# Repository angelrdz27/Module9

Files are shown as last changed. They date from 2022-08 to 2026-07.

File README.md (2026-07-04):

# Module9

This module contains all the tasks.

## Flexible Prosthetic Hand project

An out-of-the-box answer to "commercial prosthetic hands are too stiff":
instead of building a rigid hand and softening it, build a **soft hand that
stiffens on demand**. Passive fin-ray fingers conform with zero computation,
one servo drives all fingers through a self-balancing differential, and a
granular-jamming pad locks the hand rigid only when it needs to carry load.

### Documentation
| File | What it covers |
|---|---|
| `prosthetic-hand-design.md` | Design philosophy & concept directions |
| `finray-cad-print-parameters.md` | Fin-ray geometry & TPU print settings |
| `hardware-research.md` | Component research & ~$150 / ~$400 BOMs |
| `architecture.md` | System architecture (mechanical / electrical / firmware / software) |
| `ROADMAP.md` | Phased development plan with exit criteria |
| `PROCUREMENT.md` | Phase 0 order checklist + toolchain setup |
| `docs/wiring-schematic.md` | Full electrical schematic & connection tables |
| `docs/assembly-guide.md` | Step-by-step build instructions |
| `docs/test-protocol.md` | Validation tests mapped to roadmap exit criteria |

### Build artifacts
| Directory | Contents |
|---|---|
| `cad/` | Parametric OpenSCAD models (fin-ray finger, whiffle-tree, palm chassis, wrist/socket, pad mold) |
| `firmware/` | ESP32-S3 control firmware (grasp FSM, STS3215 driver, EMG intent, jamming) |
| `software/` | EMG collection, classifier training, and fatigue cycle-test scripts |
| `docs/` | Wiring schematic, assembly guide, test protocol |
| `build/` | Pre-rendered, manifold-checked STLs + preview PNGs (ready to slice) |
| `attacksurface.md` | Running security inventory of every system/vendor/tech + its exposure |
| `.claude/skills/attack-surface/` | Skill that maintains `attacksurface.md` |
| `.claude/workflows/AssessAttackSurface.js` | Workflow that assesses a surface & recommends test cadence |

### Quick start
1. Read `ROADMAP.md`; order the starter BOM via `PROCUREMENT.md`.
2. Slice the ready-made STLs in `build/stl/` (no CAD tool needed), or
   regenerate with `cad/render_all.sh` after editing parameters.
3. Flash `firmware/prosthetic_hand/`, drive it over serial (`c`/`o`).
4. Add EMG: `cd software && python emg_train.py --selftest` to check the
   pipeline, then collect real data and train.

### Current status
Phase 0/1 **design & toolchain complete**: all 12 parts render to
manifold-checked STLs (`build/`), the firmware compiles, and the EMG pipeline
passes its self-test. Remaining Phase 0/1 items are the physical
print-and-measure steps (`docs/test-protocol.md` T1–T4).

---

### Original task (Session 12)
See `Homework-12_MTMP.md` — dining philosophers problem.

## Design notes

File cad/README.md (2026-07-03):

# CAD — parametric OpenSCAD models

All parts are driven by the parameter blocks at the top of each file.
Open in OpenSCAD (or run `openscad -o out.stl file.scad` headless).

## Files
- `finray_finger.scad` — the fin-ray finger. Also contains the fingertip
  silicone-pad drape mold (`part = "mold"`).
- `whiffletree.scad` — 3-rocker tendon differential print plate.
- `palm_chassis.scad` — palm/chassis: finger + thumb mounts, servo pocket,
  tendon routing, jamming-pad recess, wrist bolt circle.
- `wrist_socket.scad` — wrist adapter (`part="adapter"`) + parametric forearm
  socket cuff (`part="cuff"`, scale to limb circumference measurements).

## Generating the finger set
Render four STLs by overriding `finger_length` (all other params shared):

```bash
for f in index:80 middle:88 ring:82 pinky:65; do
  name=${f%%:*}; len=${f##*:}
  openscad -o finger_${name}.stl -D finger_length=${len} finray_finger.scad
done
```

Thumb: reuse the index finger (80 mm) mounted on the palm at ~45° opposition.

## Variants to print in Phase 1 (see ../ROADMAP.md)
| Variant | Override |
|---|---|
| Baseline | (defaults) |
| Floating ribs | `-D floating_gap=0.4` |
| Graded wall | `-D front_wall_t=1.4 -D front_wall_t_tip=0.8` |

## Material / print quick reference
| Part | Material | Notes |
|---|---|---|
| Fingers | TPU 95A | Print lying on side face (as modeled); dry filament first |
| Rockers | PETG/PLA+ | Flat, 4 walls, 30% gyroid |
| Palm chassis | PETG/PLA+ | Palm-down, 4 walls, 30% gyroid, heat-set M3 inserts |
| Wrist adapter | PETG | Flat |
| Socket cuff | TPU 95A | Compliant, comfortable; scale to limb measurements |
| Pad mold | PLA | 0.12 mm layers, smooth cavity with brief heat-gun pass |

Full settings: `../finray-cad-print-parameters.md`.

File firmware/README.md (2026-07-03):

# Firmware — ESP32-S3 hand controller

Arduino sketch in `prosthetic_hand/`. Requires the ESP32 Arduino core
(board: "ESP32S3 Dev Module"). No external libraries — the Feetech
STS3215 driver is the self-contained `sts_servo.h`.

## Wiring

| ESP32-S3 GPIO | Connects to | Notes |
|---|---|---|
| 17 (TX1) | STS3215 data line **through 1 kΩ resistor** | half-duplex trick |
| 18 (RX1) | STS3215 data line (direct) | |
| 4 | MyoWare 2.0 ENV output | ADC1_CH3, sensor powered at 3.3 V |
| 5 | Pump MOSFET gate (logic-level N-FET, e.g. IRLZ44N/AO3400) | flyback diode across pump |
| 6 | Valve MOSFET gate | flyback diode across solenoid; energized = sealed |
| 7 | Momentary button to GND | manual open/close override |
| 15 | Status LED (+ resistor) | solid = HOLDING, blink = idle |
| GND | common ground with servo/pump supply | **required** |

Power: servo + pump from 2S Li-ion (7.4–12 V, ≥5 A BMS); ESP32 from USB or a
buck converter. Never power the servo from the devkit's 5 V pin.

A Waveshare "Bus Servo Adapter" (~$6) replaces the resistor trick if you
prefer a clean TTL interface.

## Serial interface (115200 baud)

| Command | Effect |
|---|---|
| `c` / `o` | close / open |
| `g<0-100>` | grip effort → servo load limit |
| `j` / `v` | jam / vent the stiffening pad |
| `e` | toggle EMG mode (runs 2×3 s calibration: relax, then squeeze) |
| `?` | status line |

Telemetry streams as CSV at 10 Hz:
`millis,emg_raw,emg_env,state,servo_pos,servo_load,jammed`
(state: 0=OPEN 1=CLOSING 2=HOLDING 3=RELEASING). Feed it to
`../software/emg_collect.py` or the Arduino serial plotter.

## Calibration on first assembly
1. With tendons slack, send `o`, then set `POS_OPEN` to the servo's current
   position (`?`).
2. Manually close the fingers, note the position, set `POS_CLOSED`.
3. Grip an object and watch `servo_load` in telemetry; tune `GRIP_LOAD`
   (stop-closing threshold) and `JAM_LOAD` (auto-stiffen threshold).

## EMG intent scheme (v1, single channel)
- Sustained squeeze above 35 % of calibrated range → **close**.
- Two quick pulses within 600 ms → **open** (so a long squeeze can't
  accidentally drop the object).
- Upgrade path: 3-class classifier from `../software/emg_train.py`.

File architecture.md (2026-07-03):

# System Architecture — Flexible Prosthetic Hand

## 1. System overview

```mermaid
flowchart LR
    subgraph User
        M[Forearm muscles]
    end
    subgraph Sensing
        E[MyoWare 2.0 EMG<br/>envelope out]
    end
    subgraph Controller["ESP32-S3"]
        A[ADC + filtering]
        S[Grasp state machine]
        B[STS3215 bus driver<br/>UART half-duplex]
        J[Jamming controller<br/>2x MOSFET]
    end
    subgraph Actuation
        SV[Feetech STS3215 servo]
        W[Whiffle-tree differential]
        F[4x fin-ray fingers + thumb]
    end
    subgraph Stiffness
        P[Vacuum pump]
        V[3-way solenoid valve]
        PAD[Granular jamming pad]
    end

    M --> E --> A --> S
    S --> B --> SV --> W --> F
    S --> J
    J --> P --> PAD
    J --> V --> PAD
    SV -- present load/position --> B
```

Three layers of compliance, each handling a different timescale:

| Layer | Mechanism | Timescale | Controlled by |
|---|---|---|---|
| Passive | Fin-ray wrap + silicone pads | instant | geometry (no control) |
| Grasp | Whiffle-tree tendon differential | ~0.5 s | servo position + load |
| Stiffness | Granular jamming pad | ~1–2 s | pump + valve |

Design rule: intelligence lives as low in the stack as possible. The fingers
conform with zero computation; the servo only decides *how much* to close;
firmware only decides *when* to stiffen.

## 2. Mechanical architecture

```
[STS3215 servo] -- horn --> [primary rocker 50mm]
                              /              \
              [secondary rocker 40mm]   [secondary rocker 40mm]
                 /        \                /         \
             [index]   [middle]        [ring]     [pinky]
```

- Each rocker pivots freely at its midpoint: when one finger contacts an
  object, its tendon stops moving and the rocker rotates, routing the
  remaining travel to the sibling finger. Four fingers self-balance with
  zero sensors.
- Thumb: fixed opposed position in v1 (printed at 45° opposition). v2 option:
  a Feetech SCS0009 micro bus servo on the same UART bus for abduction.
- Tendon run: servo horn → primary rocker → secondary rocker → PTFE tube
  through palm → fin-ray back-wall channel → figure-8 stopper knot at tip
  anchor. Return force: fin-ray elasticity itself (no extensor tendon in v1).
- Tensioning: each rocker end hole is a slot with an M3 grub-screw clamp so
  UHMWPE creep can be taken up without re-knotting.

Key travel calculation: full finger flexion needs ~18 mm of tendon travel.
Servo horn radius 12 mm × 120° usable sweep = 25 mm at the primary bar —
margin of ~1.4×, absorbed by the differential.

## 3. Electrical architecture

| Net | Source | Consumers | Notes |
|---|---|---|---|
| VBAT 7.4–12 V | 2S Li-ion + BMS | STS3215, pump (via MOSFET) | Servo is happiest at 7.4–12 V |
| 5 V | Buck from VBAT | MyoWare shield, solenoid | MyoWare 2.0 accepts 3.3–5 V |
| 3.3 V | ESP32 devkit LDO | ESP32-S3, logic | |

### Pin map (ESP32-S3 DevKitC; see firmware/README.md)

| GPIO | Function | Direction |
|---|---|---|
| 17 | UART1 TX → STS3215 data (through 74HC126 or direct with 1k resistor trick) | out |
| 18 | UART1 RX ← STS3215 data | in |
| 4 | EMG envelope (ADC1_CH3) | in |
| 5 | Pump MOSFET gate | out |
| 6 | Solenoid valve MOSFET gate | out |
| 7 | Mode button (INPUT_PULLUP) | in |
| 15 | Status LED | out |

The STS3215 uses single-wire half-duplex TTL. Cheapest interface: tie TX to
the data line through a 1 kΩ resistor and connect RX directly — TX idles high
and the resistor lets the servo win the line when replying. A Waveshare bus
driver board (~$6) is the tidy alternative.

### Power budget (worst case)
| Load | Current |
|---|---|
| STS3215 stall @12 V | ~2.5 A (limit in firmware to 1.5 A equiv. load) |
| Vacuum pump | ~0.4 A |
| Solenoid | ~0.2 A |
| ESP32 + EMG | ~0.15 A |
| **Peak** | **~3.2 A** → 2S 18650 pack (≥5 A rated BMS) is sufficient |

## 4. Firmware architecture (`firmware/prosthetic_hand/`)

Single-core superloop at 100 Hz (no RTOS needed at this rate):

```
loop @100Hz:
  emg_sample()        # ADC read → 20-sample moving average → envelope
  intent = classify() # dual-threshold hysteresis (or serial command)
  fsm_step(intent)    # OPEN / CLOSING / HOLDING / RELEASING
  servo_update()      # goal position; stop closing when load > limit
  jamming_update()    # stiffen when HOLDING && load high; vent on release
  telemetry @10Hz     # CSV over USB serial for plotting / data collection
```

### Grasp state machine

| State | Entry condition | Servo behavior | Jamming |
|---|---|---|---|
| OPEN | release intent / boot | goal = open position | vented |
| CLOSING | close intent | ramp toward closed at fixed speed | vented |
| HOLDING | servo load > grip threshold, or full travel | hold position, duty-limit if hot | stiffen if load > jam threshold for >1 s |
| RELEASING | open intent | ramp to open | vent immediately (valve first, then pump off) |

Load-based grip: instead of position targets per object, the servo closes
until *present load* (register 60) crosses the grip threshold — the
mechanical differential + fin-rays have already shaped the grasp by then.
This is impedance-ish control with zero tactile sensors.

### EMG intent (v1: single channel)
- Calibration at boot: 3 s of rest → noise floor; user squeezes once → max.
- Close intent: envelope > 35 % of (max − floor), with 150 ms debounce.
- Open intent: quick double-pulse within 600 ms (co-contraction pattern),
  so a single sustained squeeze can't accidentally open the hand.
- v2 (`software/`): 3-class ML classifier (rest/close/open) on windowed
  features, exported thresholds or TFLite-Micro model.

## 5. Software architecture (`software/`)
- `emg_collect.py` — logs the firmware's 10 Hz telemetry CSV to labeled
  session files (`rest.csv`, `close.csv`, `open.csv`).
- `emg_train.py` — windows the data (200 ms, 50 % overlap), extracts
  MAV / RMS / waveform-length / zero-crossings, trains a RandomForest,
  reports confusion matrix, and prints firmware-ready threshold constants.
  TFLite-Micro export is the documented upgrade path.

## 6. Interfaces & contracts
- **Serial command protocol** (USB, 115200 baud, newline-terminated):
  `o` open, `c` close, `g<0-100>` grip effort, `j`/`v` jam/vent, `?` status.
  This is also the test interface for Phase 2 before EMG exists.
- **Telemetry CSV**: `millis,emg_raw,emg_env,state,servo_pos,servo_load,jammed`
- **CAD ↔ hardware contract**: all printed parts reference the parameter
  block at the top of each `.scad` file; tendon channel Ø2.5 mm, PTFE 2 mm OD,
  M3 fasteners throughout.

## 7. Failure-mode behavior
| Failure | Detection | Response |
|---|---|---|
| Servo over-load / stall | present load > 90 % for 2 s | back off 5°, duty-limit |
| EMG sensor unplugged | envelope pinned at rail | freeze state, LED blink, fall back to serial commands |
| Vacuum loss (membrane leak) | pump duty > 80 % sustained | disable jamming, notify via telemetry |
| Brown-out under stall | ESP32 brown-out detector | servo torque-off on reboot, hand stays passively compliant (fail-soft — a key advantage over rigid hands) |

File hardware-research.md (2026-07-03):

# DIY Flexible Prosthetic Hand — 2025/2026 Component Research & BOM

*Scope: TPU fin-ray fingers, fishing-line tendons, single-servo whiffletree
differential, silicone fingertip pads, with later granular-jamming stiffness
and EMG control. All prices are **approximate** (USD, mid-2026) and shift with
retailer/quantity.*

---

## 1. Actuators

The architecture uses **one main actuator** pulling a whiffletree, so you want
high stall torque, position feedback (ideally), and enough travel to close all
fingers. Serial-bus servos win here because they give torque + encoder
feedback + daisy-chaining on 3 wires, which matters once you add EMG and want
current-based grip feedback.

| Model | Type | Stall torque | Size / weight | Interface | Price (approx) |
|---|---|---|---|---|---|
| **Feetech STS3215** (C018, 12V) | Serial bus, magnetic encoder | ~30 kg·cm @12V (19.5 kg·cm @7.4V C001) | 40×20×40 mm, ~60 g | TTL serial bus (daisy-chain), 12-bit abs encoder | **~$14–27 each** |
| **Dynamixel XC330-M288-T** | Serial bus, metal gear | ~0.6 N·m (~6 kg·cm) | ~34 mm tall, ~23 g | TTL, 4096-step encoder, current/temp feedback | ~$45–55 |
| **Dynamixel XL330-M288-T** | Serial bus, plastic gear | 0.52 N·m (~5.3 kg·cm) @5V | 20×34×26 mm, **18 g** | TTL serial bus, full feedback | ~$27 |
| **DS3218 / DS3218MG** (ANNIMOS) | Standard PWM digital, metal gear | 19–21.5 kg·cm | 40×20×40.5 mm, ~60 g | PWM (no feedback) | ~$15–20 |
| **Actuonix PQ12-63-12-S** | Micro linear actuator | 30 N push @ 8 mm/s, 20 mm stroke | ~34 mm body | PWM/analog + position feedback | ~$70–90 |
| **Actuonix L12** | Linear actuator (longer stroke) | up to ~40–80 N depending on gearing | 50–100 mm stroke | PWM/RC/analog | ~$70–110 |

**Picks:**
- **Pick the Feetech STS3215 if** you want the best torque-per-dollar and
  position/current feedback for a whiffletree main pull — it's the de-facto
  open-source robotics servo (SO-ARM100/101) and is cheap enough to buy
  spares. **Recommended default.**
- **Pick the Dynamixel XL330/XC330 if** weight and clean feedback
  (current-based grip sensing) matter more than cost, e.g. a wearable
  prosthesis where 18 g and precise control beat raw torque.
- **Pick the DS3218 if** you just want the cheapest strong "pull the tendon
  bundle" actuator for a first mechanical prototype and will do position
  control open-loop off a microcontroller PWM pin.
- **Linear actuator (Actuonix PQ12/L12) if** you prefer a direct linear tendon
  pull with built-in position feedback and no horn geometry — cleaner force
  curve, but pricier and slower.

---

## 2. Tendon Materials

Both Spectra and Dyneema are UHMWPE (same fiber family); "PE braid" fishing
line is the accessible form. Key properties: **near-zero stretch,
steel-comparable strength-to-weight, excellent abrasion resistance**, but it
*creeps* under sustained load and can saw through soft plastic anchors, so
route through PTFE and use metal/round anchor points.

| Material | Recommended rating | Behavior | Use for |
|---|---|---|---|
| **Braided UHMWPE (Spectra/Dyneema/PE braid)** — e.g. PowerPro, Berkley | **50–100 lb test** for a full-hand main tendon; 30–50 lb for individual fingers | Very low stretch, high fatigue life, low friction; slowly creeps, needs good knots (Palomar) or crimps | **Primary tendon material — recommended** |
| **Nylon monofilament** | 30–80 lb | Stretches noticeably (elastic return can help passive extension), UV/fatigue weaker, cheaper | Return/antagonist springs, non-critical routing, prototyping |
| **Bowden cable (steel inner + housing)** | n/a (steel) | No stretch, high push/pull, heavier, more friction | Long routing runs through the forearm where you need push as well as pull |
| **PTFE tube (Bowden liner, 2 mm OD / ~1 mm ID, "Capricorn"-style)** | — | Ultra-low-friction routing sheath; keeps braid from sawing plastic | Route tendons around every direction change |

**Picks:**
- **Pick 65–80 lb PE braid + PTFE liner if** you want the standard, reliable
  tendon setup (a 100 lb PowerPro line is exactly what research tendon-driven
  hands like the Seed Robotics RH8D use). **Recommended.**
- **Pick nylon mono if** you specifically want built-in stretch for passive
  finger extension, or as a cheap disposable prototype line.
- **Add short PTFE tube segments** at all fin-ray entry/exit points and pulley
  bends — this is the single biggest longevity upgrade for fishing-line
  tendons (~$8–12 for 1 m of Capricorn tube).

*Cost: a spool of quality PE braid is ~$15–25 and will last many builds.*

---

## 3. EMG Sensing (later iteration)

| Board | Channels | Interface | Ease | Price (approx) |
|---|---|---|---|---|
| **MyoWare 2.0 Muscle Sensor** (SparkFun DEV-21265) | 1 (envelope + raw out) | Analog out, snap-on shields (LED/power/cable/BLE) | Easiest — plug-and-play, wearable, shield ecosystem | ~$38 (sensor); Basic/Wireless kits ~$70–110 |
| **BioAmp EXG Pill** (Upside Down Labs) | 1 (EMG/ECG/EOG/EEG) | Analog out to any ADC | Easy, needs gel electrodes + cable; publication-grade signal | ~$25–35 each (2-pack ~$69) |
| **uMyo** (Ultimate Robotics / uDevices) | 1 wireless + IMU | BLE / nRF24 / USB, 9 g wearable PCB | Easy wireless, great for untethered; add nRF24 to read on Arduino | ~$30–40 |
| **Gravity / OYMotion (DFRobot SEN0240 etc.)** | 1 | Analog | Easy, robust analog front-end | ~$35–45 |

**Picks:**
- **Pick MyoWare 2.0 if** you want the lowest-friction start: it outputs a
  clean rectified envelope you can threshold on any ADC pin, and the shield
  ecosystem (power, BLE, cable) is genuinely beginner-friendly.
  **Recommended first EMG.**
- **Pick BioAmp EXG Pill if** you want the best signal quality per dollar and
  plan to do real ML classification — you get the raw waveform for feature
  extraction, and it's cheap enough to run 2–3 channels for multi-gesture
  control.
- **Pick uMyo if** you want wireless, wearable EMG (untethered forearm band)
  with an onboard IMU for sensor-fusion gestures.

*For TinyML multi-gesture control, budget 2–3 channels (e.g. 3× BioAmp EXG
Pill ≈ $75–90).*

---

## 4. Microcontrollers

| Board | CPU / ML | Wireless | Notes | Price (approx) |
|---|---|---|---|---|
| **ESP32-S3** (DevKit / XIAO ESP32-S3) | Dual-core 240 MHz, vector/SIMD for ML inference | Wi-Fi + BLE | Best all-rounder: enough ADC channels, cheap, huge community, runs TFLite-Micro; XIAO form factor fits in a forearm | ~$8–15 |
| **Teensy 4.0 / 4.1** | Cortex-M7 @600 MHz (overclock ~1 GHz) | none (4.1 has Ethernet) | Fastest MCU here; excellent ADC + tons of PWM/serial for many servos; ideal if you outgrow ESP32 compute | ~$20–30 |
| **Arduino Nano 33 BLE Sense (Rev2)** | Cortex-M4F @64 MHz + IMU | BLE | The canonical TinyML board — best-documented TensorFlow Lite Micro workflow, onboard IMU | ~$45–55 |
| **RP2040 / RP2350 (Pico 2)** | Dual M0+/M33; RP2350 adds more compute | RP2350 W has Wi-Fi/BLE | Cheap, PIO is great for driving many servos/serial buses precisely | ~$4–8 |

**Picks:**
- **Pick ESP32-S3 if** you want one board to do servo control + EMG ADC +
  future on-device ML + wireless telemetry. Best value and future-proofing.
  **Recommended default.**
- **Pick Teensy 4.x if** your EMG classifier gets heavy (higher sample rates,
  more channels, real-time DSP) — raw horsepower and superb peripheral count.
- **Pick Nano 33 BLE Sense if** you're following TinyML tutorials directly —
  the gesture/EMG classification toolchain is most turnkey here.
- **Pick RP2350/Pico 2 if** you want a rock-bottom-cost controller and will
  use PIO to bit-bang the Feetech serial bus and PWM cleanly.

---

## 5. Granular Jamming Supplies (iteration 2)

The classic "coffee-balloon" universal jamming gripper (Brown/Amend/Jaeger,
PNAS 2010) is the reference; here you'd apply it as **variable-stiffness
pads/palm**.

| Item | Options | Notes | Price (approx) |
|---|---|---|---|
| **Vacuum pump** | 12V mini diaphragm (SparkFun ROB-10398 style); **SC3101PM** (Skoocom, very small 3–5V); generic 6–12V diaphragm | Diaphragm pumps are one-way (can't reverse to inflate). ~-40 to -70 kPa is plenty for jamming | ~$15–30 |
| **Solenoid valve** | 2-way/3-way 6–12V normally-closed (e.g. small barbed pneumatic solenoid) | Lets you hold vacuum without running pump; 3-way vents to atmosphere to un-jam fast | ~$6–12 |
| **Membrane** | Latex balloons / party balloons; thin latex sheet; nitrile finger cots for small pads | Balloons are the cheap standard; latex sheet lasts longer | ~$5–10 |
| **Granular media** | **Ground coffee** (low density, best jamming-hardness/weight — the classic pick); **glass beads** (harder grip, heavier); ground rice/sand as alternatives; EPS/soft beads give *higher* force but less rigidity | Coffee = best all-round for lightweight pads; glass beads if you want maximum rigidity | ~$5 |
| Check valve + barbed fittings + silicone tubing | 4 mm / 6 mm ID tubing | Plumbing | ~$8 |

**Picks:**
- **Pick a 12V mini diaphragm pump + 3-way solenoid + coffee-filled latex pad
  if** you want the proven, cheapest variable-stiffness route. **Recommended.**
- **Pick glass beads if** you need maximum locked rigidity (heavier);
  **coffee grounds if** weight matters (fingertip/palm pads).
- Budget ~$40–55 total for a working single-chamber jamming subsystem.

---

## 6. Silicone for Fingertip Pads

| Product | Shore hardness | Feel / use | Buy small qty | Price (approx) |
|---|---|---|---|---|
| **Ecoflex 00-30** (Smooth-On) | Shore 00-30 (very soft), ~900% elongation | Skin-like, grippy, deformable fingertip pads; skin-safe | Trial unit (~1 lb total) | **~$40–52 trial** |
| **Dragon Skin 10** (Smooth-On) | Shore 10A (firmer, tougher) | More durable, higher tear strength; good for structural fin-ray reinforcement or grippier tougher pads | Trial unit | ~$40–55 trial |
| **Ecoflex 00-50** | 00-50 (mid) | Compromise: softer than Dragon Skin, tougher than 00-30 | Trial unit | ~$45 |

**Picks:**
- **Pick Ecoflex 00-30 if** you want maximally compliant, high-friction,
  skin-like fingertip pads for adaptive grasp. **Recommended for pads.**
- **Pick Dragon Skin 10 if** you want durability/tear resistance (pads that
  survive abrasion, or flexible joint webbing).
- Buy **trial units** direct from Smooth-On or resellers (Douglas & Sturgess,
  Reynolds); one trial kit casts many fingertip pads. Add a
  **Slacker/Thi-Vex** additive later if you want softer or thixotropic
  (non-drip) mixes.

---

## 7. TPU Filaments (fin-ray fingers)

Fin-ray fingers need flexibility but enough backbone to transmit tendon
force — **95A is the sweet spot** for fin-ray; 85A for very compliant tips;
Varioshore lets you grade stiffness within one print.

| Filament | Shore | Printability | Price/kg (approx) |
|---|---|---|---|
| **NinjaFlex 85A** (NinjaTek) | 85A, ~660% elong | Softest common FDM TPU; **direct-drive only**, 20–25 mm/s, no retraction, must be dry | ~$45 |
| **NinjaTek Cheetah 95A** | 95A | Engineered to print on **Bowden** extruders too; forgiving, fast | ~$40–50 |
| **Polymaker PolyFlex TPU95** | 95A | Easy, reliable, good surface | ~$30 |
| **eSUN TPU 95A** | 95A | Best value, widest colors incl. translucent; QC "good not great" | **~$20** |
| **Overture TPU 95A** | 95A | Cheap, reliable budget option | ~$20–25 |
| **colorFabb varioShore TPU** | **~92A (60–70% flow) down to ~55A fully foamed** | Foaming — vary stiffness/density by temp & flow (200–250 °C expands ~1.6×); great for graded fin-ray | ~$52 |

**Picks:**
- **Pick eSUN or Overture TPU 95A if** you want cheap, reliable fin-ray
  fingers and have a direct-drive printer. **Recommended default for
  structure.**
- **Pick NinjaTek Cheetah 95A if** you're on a Bowden printer (Ender-style) —
  it's specifically formulated not to jam.
- **Pick NinjaFlex 85A if** you want very compliant fingers/webbing and have
  direct drive + patience.
- **Pick varioShore TPU if** you want to grade stiffness within a single
  finger (stiff base → soft tip) — ideal for advanced fin-ray tuning.

---

## 8. Reference Open-Source Projects

- **Yale OpenHand Project** (GrabLab) — the canonical open-source
  underactuated hand line (Model T, T42, M2, etc.): 3D-printed,
  tendon-driven, differential/underactuated fingers. **Study first — closest
  to this architecture.** eng.yale.edu/grablab/openhand
- **Whiffletree differential papers** — Kontoudis & Kyriakopoulos /
  Leddy & Dollar; the Frontiers/PMC review *"On Differential Mechanisms for
  Underactuated, Lightweight, Adaptive Prosthetic Hands"* and the
  *selectively-lockable whiffletree* work (144 postures from one motor).
  **Essential reading for the single-servo differential.**
- **exiii HACKberry** — fully open 3D-printable EMG bionic hand
  (Arduino-based, ~$200 BOM). exiii-hackberry.com — good for EMG integration
  + socket/wrist design.
- **Open Bionics — Brunel Hand 2.0** — open design files on GitHub
  (Open-Bionics/Brunel) and Thingiverse; tendon-driven, research-grade. Good
  mechanical reference.
- **Tactile SoftHand-A** (arXiv 2406.12731, 2024) — 3D-printed,
  highly-underactuated anthropomorphic hand with **antagonistic tendons** +
  tactile sensing. Recent and directly relevant to soft tendon hands.
- **e-NABLE / LimbForge** — community body-powered and simple designs
  (Phoenix Hand, Unlimbited Arm); best for socket, cosmesis, and fit patterns
  rather than actuation.
- **HANDSON Hand (CYBATHLON 2024, PMC11939478)** — recent competition-grade
  design notes worth skimming for real-world robustness lessons.

---

## Suggested ~$150 Starter BOM (mechanical proof-of-concept)

*Goal: TPU fin-ray fingers, fishing-line tendons, single-servo whiffletree,
silicone pads, basic microcontroller control.*

| Item | Choice | Qty | Price (approx) |
|---|---|---|---|
| Main actuator | Feetech STS3215 (serial bus, feedback) | 1 | $20 |
| Microcontroller | ESP32-S3 (XIAO or DevKit) | 1 | $12 |
| Servo/bus driver + wiring | TTL bus adapter + buck converter + connectors | 1 | $12 |
| TPU filament | eSUN / Overture TPU 95A, 1 kg | 1 | $22 |
| Tendon line | PE braid 65–80 lb spool | 1 | $18 |
| PTFE routing tube | Capricorn 2×1 mm, 1 m | 1 | $10 |
| Fingertip silicone | Ecoflex 00-30 trial unit | 1 | $45 |
| Fasteners / springs / anchors / crimps | assorted | — | $12 |
| **Total** | | | **≈ $151** |

*(Swap to a DS3218 at ~$16 to shave cost, or add a second STS3215 for a
driven thumb.)*

---

## Suggested ~$400 "Iteration 2" BOM (adds granular jamming + EMG)

*Builds on Starter BOM; adds variable stiffness and myoelectric control.*

| Item | Choice | Qty | Price (approx) |
|---|---|---|---|
| **(Carryover: starter build)** | mechanical hand as above | 1 | ~$151 |
| Upgrade main actuator | Dynamixel XC330-M288-T (current feedback for grip force) | 1 | $50 |
| EMG sensing | BioAmp EXG Pill | 2 | $60 |
| EMG sensing (easy channel) | MyoWare 2.0 sensor + cable shield | 1 | $50 |
| Gel/electrodes + electrode cables | consumables | — | $15 |
| Vacuum pump | 12V mini diaphragm | 1 | $22 |
| Solenoid valve (3-way) + check valve | pneumatics | 1 set | $15 |
| Membrane + granular media | latex + ground coffee (+ glass beads sample) | — | $12 |
| Pneumatic tubing + barbed fittings + MOSFET driver board | plumbing + switching | — | $20 |
| varioShore TPU (graded-stiffness fingers) | colorFabb, 700 g | 1 | $40 |
| Battery + power management (Li-ion pack + BMS/buck) | — | 1 | $25 |
| **Total** | | | **≈ $410** |

*(Trim toward $360 by using 3× BioAmp EXG Pill instead of MyoWare, or reusing
the starter STS3215 instead of upgrading to Dynamixel.)*

---

### Practical notes / gotchas
- **Tendon anchoring** is the #1 failure point: use PTFE at every bend, and
  terminate braid with a Palomar knot or a metal crimp around a smooth post —
  braid saws through raw printed TPU/PLA.
- **Diaphragm vacuum pumps are one-directional** — you can't reverse one to
  inflate the jamming bag; use the 3-way solenoid to vent-to-atmosphere for
  fast un-jamming.
- **Print TPU dry** (dry box / 50 °C for a few hours). 95A on direct-drive is
  easy; on Bowden use Cheetah 95A specifically.
- **EMG needs a common reference electrode** and clean skin prep; start with
  MyoWare's envelope output for thresholding before moving to raw-signal ML
  on BioAmp.
- For **current-based grip feedback** (adaptive grasp without tactile
  sensors), the Dynamixel XC330 or a current-sensing shunt on the Feetech
  supply is the cheapest path.

*All prices approximate, mid-2026, single-unit retail; expect 10–30% swings
by vendor and quantity.*

---

## Addendum — verified pricing & extra options (second research pass, July 2026)

A second, source-verified pass on actuators and tendons produced these
corrections and additions:

### Actuators
- **Dynamixel XL330-M288-T**: confirmed **$27.49** at robotis.us, 18 g, true
  current (torque) control at 5 V — the best option for grip-force control by
  weight. 6 units ≈ $165.
- **Dynamixel XC330-T288-T**: verified **~$103** at robotis.us (pricier than
  first-pass estimate — the M288/T288 variants differ; check the exact SKU
  before budgeting).
- **Waveshare ST3215** (Feetech-based): 30 kg·cm @12V, 360° magnetic encoder,
  servo/motor mode switch, up to 253 on one bus — **~$25–27** and easy to buy
  on Amazon. Good STS3215 alternative with Western retail availability.
- **Feetech SCS0009**: 9 g-class micro *bus* servo, 2.3 kg·cm, **~$7** — cheap
  option for thumb abduction or individual finger tweaks on the same bus.
- **STS3215 ecosystem note**: this is the servo in Hugging Face
  **LeRobot SO-100/SO-101** arms — Python drivers (`feetech-servo-sdk`,
  lerobot) and a large community already exist.
- **Budget linear option**: N20 gearmotor + M3/M4 lead-screw shaft, **$3–10**
  each — no feedback or limit switches (add a pot yourself), slow, but five
  of them cost less than one Actuonix.

### Tendons
- **KastKing SuperPower braid** (8-strand UHMWPE), 65–80 lb × 327 yd:
  **~$10–16** on Amazon — best value; PowerPro 65 lb/150 yd runs ~$20–25.
- Recommended spec confirmed: **65–100 lb test (~0.4–0.55 mm dia)** — routes
  through 1 mm channels with load margin; stretch <1–3 %.
- **UHMWPE caveats**: creeps slowly under sustained tension (make tendon
  terminations re-tensionable with adjustment screws) and melts at ~144 °C —
  keep away from hot ends when printing repairs.
- **Kevlar braid** (100 lb, ~0.8 mm, ~$8–12/100 ft): zero creep and
  heat-proof, but **worse flex-fatigue over small pulleys** than UHMWPE —
  only pick it where creep or heat genuinely matters.
- **PTFE sizing**: 1 mm ID × 2 mm OD microtube (~$8–10 for 5 m) fits 0.5 mm
  tendons in tight finger channels; standard 2 mm ID × 4 mm OD Bowden tube
  for palm/forearm runs.
- **Nylon mono verdict**: stretches 15–25 % and creeps badly — use only for
  elastic return, never as a flexor tendon.

### Verified budget summaries (actuation + tendons only)
- 6× DS3218 + KastKing 80 lb braid + PTFE ≈ **$90–100**
- 6× Feetech STS3215 (smart bus) ≈ **$100–120**
- 6× Dynamixel XL330 (lightweight, current control) ≈ **$180**

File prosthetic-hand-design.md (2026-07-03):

# Flexible Prosthetic Hand — Design Brainstorm

## Problem
Commercial prosthetic hands are too stiff. The stiffness comes from their design
philosophy, not just their materials: rigid links, one motor per joint,
gearboxes, and position control. A human hand is the opposite — compliant by
default, recruiting stiffness only when needed.

**Core design principle: don't build a stiff hand and soften it.
Build a soft hand and add stiffness on demand.**

## Design directions

### 1. Compliant mechanisms & soft structures
- Replace pin joints with printed flexures (living hinges): the finger becomes
  one monolithic part with no joints to jam or wear.
- **Fin Ray effect fingers**: a triangular flexible structure that passively
  wraps around any object it touches — the geometry does the grasping, with no
  sensors or control loop. Printable in TPU.

### 2. Underactuation with adaptive synergies
- One motor drives multiple tendons through a differential (whiffle-tree or
  floating pulleys).
- When one finger contacts the object, tension automatically flows to the
  remaining fingers until the whole hand conforms.
- Reference: Pisa/IIT SoftHand — a single actuator grasps eggs, hammers, and
  sheets of paper because the object shapes the grasp.

### 3. Variable stiffness — soft by default, rigid on demand
- **Layer jamming / granular jamming**: a finger filled with granular media or
  stacked flexible sheets is floppy until a small vacuum is applied, then it
  locks rigid. Stiffness becomes a switchable state.
- **Antagonistic tendons**: co-contract opposing tendons to stiffen a joint,
  exactly as human muscles do.
- **Phase-change elements**: shape-memory alloys or low-melting-point polymers
  in the joint that soften/harden electrically.

### 4. Gradient materials (bio-inspired)
- Human fingertip: bone → tendon → fat pad → ridged skin.
- Reproduce with multi-material fabrication: rigid PLA core, TPU flexure
  joints, cast silicone fingertip pads.
- The soft pad is functional, not cosmetic — it provides grip friction and
  enables delicate handling.

### 5. Compliant control
- **Impedance/force control** ("push with 2 N") instead of position control
  ("move to 40°").
- **Series elastic actuation**: a spring between motor and tendon absorbs
  shocks and makes force sensing cheap.
- **Continuous EMG regression** instead of discrete grip modes, so the user
  modulates *how hard*, not just open/close.

## First prototype (low cost, ~1 weekend)
1. 3D-print fin-ray fingers in TPU (95A shore hardness).
2. Route fishing-line tendons through the palm.
3. Single hobby servo + whiffle-tree differential for adaptive grasp.
4. Cast silicone (e.g. Ecoflex) fingertip pads for friction.
5. Test grasps: egg, water bottle, pen, sheet of paper.

**Iteration 2 differentiator**: add granular-jamming stiffening — a hand that
is gentle by default and locks rigid on demand (e.g. carrying a heavy bag).

## Key references to study
- Fin Ray Effect grippers (Festo)
- Pisa/IIT SoftHand (adaptive synergies, underactuation)
- Yale OpenHand project (open-source underactuated hands)
- Jamming-based variable stiffness (iRobot/Chicago universal jamming gripper)
- Series elastic actuators (Pratt & Williamson)

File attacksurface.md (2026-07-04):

# Attack Surface Inventory

> **Living document.** Maintained via the `attack-surface` skill; findings and
> cadences are (re)generated by the `AssessAttackSurface` workflow. Add/adjust
> an entry whenever a system is proposed, deployed, changed, assessed, or retired.

## Scope & honesty note
This inventory currently covers **only what is visible in the `angelrdz27/Module9`
repository** — the sole repo in this session's scope. It is therefore **partial by
design**. The categories the org cares about but that have **no evidenced members
yet** (cloud hosts, domains/sites, databases, first-party APIs, most SaaS vendors,
identity/OAuth/SSO, VPN/network) are kept as **placeholders** below so the gaps are
visible rather than silently implied-complete.

**To widen coverage:** add more repos to the session (`list_repos` → `add_repo`),
or fill the placeholder sections with systems you know about. Nothing here is
fabricated — absence of a system means "not seen," not "assessed as safe."

## Assessment summary (last run: 2026-07-04)
Assessed by the `AssessAttackSurface` workflow — **83 agents**, enumerate →
analyze (5 lenses) → adversarial verify → cadence — plus a manual cross-check.
Headline results:
- **No secrets** anywhere in history (verified across all commits). **No CI/CD**,
  so also no automated scanning or branch gating today.
- **No network exposure**: firmware initializes **no radio** (verified — zero
  `WiFi/BLE/OTA/TCP` references); host tooling opens **no socket**. Everything is
  `physical-only` or `local-only` right now.
- The dominant risk is **unauthenticated control of a body-worn actuator** — fine
  under today's physical-only model, dangerous the moment any radio is enabled.
- One **safety defect the assessment found has already been fixed**: the serial
  reader could block the 100 Hz control loop for up to 1 s (see firmware entry).

## Legend
- **Exposure/audience:** `public` · `internal` · `behind VPN` · `token-required` · `OAuth-gated` · `physical-only` · `local-only` · `none`
- **Severity:** `info` < `low` < `medium` < `high` < `critical`
- **Verification:** `CONFIRMED` (evidenced) · `PLAUSIBLE` (design-level/likely) · `RESOLVED` (fixed) · `self-assessed`
- **Criticality:** blast radius × data sensitivity × safety impact.

---

## 1. Repositories / Version Control

### GitHub repo — `angelrdz27/Module9`
- **Classification:** repo / VCS (source hosting)
- **Technology:** Git; GitHub platform. Content: Markdown, Python, Arduino/C++, OpenSCAD, committed STL/PNG binaries. 47 tracked files, ~8 commits, single author, linear history.
- **Hosting:** third-party (**GitHub**). Session pushes traverse an ephemeral local git proxy (`127.0.0.1:41729`) — a session artifact, not a durable asset.
- **Deployed assets:** the prosthetic-hand project + Module9 coursework; branches `main` and `claude/flexible-prosthetic-hands-cmhdd6`; `.claude/` automation (this skill + workflow).
- **Authentication:** into GitHub via the owner's account; session writes use a token brokered by the proxy (no credential stored in git config — userinfo is a bare `local_proxy@`).
- **Exposure / audience:** `UNKNOWN — needs input` whether the repo is **public or private** (the single most important unknown). No running service is exposed; the surface is source/commit integrity + access control.
  - reachable by: internet (github.com), to whoever has repo visibility.
- **Security mechanisms (in place):** git history/audit trail; GitHub account controls; `.claude/settings.local.json` grants only a single narrow Bash permission (no broad grants).
- **Common issues / misconfigurations for GitHub repos:** committed secrets; missing branch protection (force-push/history rewrite); unintended public exposure; over-permissive collaborators; account without 2FA; Dependabot off; unsigned commits.
- **Known gaps / findings:**
  - `info` — **secret scan clean across ALL commits** (`git rev-list --all`): no keys/tokens/private-keys/`.env`/credential files. *(CONFIRMED)*
  - `medium` — repo public/private status unconfirmed; if public, firmware + biometric-adjacent code is world-readable. *(needs input)*
  - `low` — **git remote is plaintext HTTP** (`http://…`, both fetch & push); no transport TLS. Confined to the loopback proxy so real exposure is local-host only. *(CONFIRMED)*
  - `low` — no branch protection / signed commits / `SECURITY.md` / `CODEOWNERS` evident; commit provenance rests entirely on GitHub-side account control. *(PLAUSIBLE)*
  - `low` — **no CI/CD** (no `.github/workflows`): no automated secret-scan, dependency-audit, or branch gating runs on push. *(CONFIRMED)*
- **Test cadence:** on **every push** — automated secret + dependency scan and firmware static analysis as a CI gate (**none exists today — stand one up**). **Quarterly** — manual repo-config/access review. **Blocking** security review before merging any wireless/OTA/network code.
- **Criticality:** medium · **Test cost:** low
- **Last reviewed:** 2026-07-04 · **Last assessed:** 2026-07-04 (workflow + manual)

---

## 2. Embedded / IoT

### ESP32-S3 prosthetic-hand firmware
- **Classification:** embedded / IoT — **safety-relevant** (drives a body-worn actuator)
- **Technology:** Arduino C++ on ESP32-S3; UART half-duplex to a Feetech STS3215 servo (`sts_servo.h`, 1 Mbaud); ADC for MyoWare EMG; GPIO/MOSFET for pump + solenoid. Planned: TFLite-Micro EMG model, wireless telemetry.
- **Hosting:** self-hosted on the device (physical / ephemeral).
- **Deployed assets:** `prosthetic_hand.ino` (100 Hz grasp FSM), `sts_servo.h` (bus driver), serial command protocol (`o c g j v e ?`), GPIO7 override button.
- **Authentication:** **NONE** on the serial command interface (USB-CDC, 115200) or the STS3215 bus. WiFi/BLE radios exist on the SoC but are **not enabled**.
- **Exposure / audience:** `physical-only` — **CONFIRMED**: firmware calls only `Serial.begin`/`Serial1.begin`, includes only `<Arduino.h>` + `sts_servo.h`, and a grep for `wifi|ble|esp_now|ota|tcp|udp|http|mqtt|socket` returns zero matches. ⚠️ Enabling any radio (roadmap Phase 5) escalates this to remote/RF.
  - reachable by: anyone with physical/USB access (full unauthenticated actuation) or the GPIO7 button; RF range only if radios are later enabled.
- **Security mechanisms (in place):** **fail-soft on brown-out** (servo torque-off → passive compliance, not clamp); grip/overload/jam load limits + `constrain(pct,0,100)` clamp; double-pulse-to-open guard; bus replies are checksum-validated, length-bounded (`buf[got++]` gated by `got<8`), and timeout-guarded; command parser input is bounded/safe (no overflow found).
- **Known gaps / findings (most severe first):**
  - `high` — **unauthenticated control of a body-worn actuator** over serial; any connected host/process gets full open/close/grip/jam control. Acceptable only under the physical-only model; must gain an auth/authorization layer before any radio path. *(CONFIRMED)*
  - `medium → RESOLVED 2026-07-04` — **blocking serial read stalled the 100 Hz safety loop** for up to 1 s (`Serial.readStringUntil('\n')` on a partial line). **Fixed**: replaced with non-blocking, bounded, per-byte line accumulation (`serialIntent()` + `dispatchCommand()`). *(CONFIRMED, fixed)*
  - `medium` — **grasp FSM trusts unauthenticated servo-bus load values**; a forged/implausible `present_load` directly drives crush-force decisions. Recommend clamping/rate-limiting physically-implausible load jumps between reads. *(CONFIRMED)*
  - `medium` — **no hardware root of trust**: Secure Boot v2 / flash encryption disabled, ROM download + JTAG at defaults ⇒ firmware dump/tamper/replace over USB; every in-firmware safety limit is bypassable by reflash. Enable before any field/clinical build. *(PLAUSIBLE — platform default)*
  - `medium` — **no authorization tiers**: read-only (`?`), actuation (`c/o/g/j/v`), and mode-change share one (absent) trust level. Split read-only vs control. *(CONFIRMED)*
  - `medium` — **planned wireless has no auth/pairing design**; treat radio enablement as a gated, security-reviewed change (BLE bonded pairing w/ MITM protection, signed OTA). *(PLAUSIBLE — future)*
  - `low` — **build toolchain unpinned** (ESP32 Arduino core version is prose-only); add a `platformio.ini`/`sketch.yaml` pinning core + board for reproducible builds. *(CONFIRMED)*
  - `low` — `String` use in the hot loop is a minor heap-fragmentation (availability) concern. *(self-assessed)*
- **Test cadence:** **every firmware push/PR** — static analysis (`cppcheck`/`clang-tidy`, `-Wall -Wextra`) + human review of FSM safety bounds (GRIP/OVERLOAD/JAM thresholds, vent paths). **Before fitting to a person / per release** — hardware-in-the-loop fault injection + measured crush-force test. **On any bootloader/provisioning change** — eFuse/Secure-Boot verification. **Quarterly** — host dependency scan + threat-model review. **Annually, and mandatory before any wireless feature** — independent security + safety review.
- **Criticality:** high · **Test cost:** low (static/review) → medium (hardware tests)
- **Last reviewed:** 2026-07-04 · **Last assessed:** 2026-07-04 (workflow + manual)

---

## 3. Local Tooling / Supply Chain

### EMG Python toolchain
- **Classification:** local tooling / software supply chain
- **Technology:** Python 3.11+; `pyserial`, `numpy`, `scikit-learn` (`software/requirements.txt`). Also OpenSCAD + `render_all.sh` (local build helpers).
- **Hosting:** self-hosted on the operator's machine; **no network listener**.
- **Deployed assets:** `emg_collect.py`, `cycle_test.py` (serial → CSV), `emg_train.py` (CSV → RandomForest + thresholds).
- **Authentication:** none required; serial-port + filesystem access are OS-mediated.
- **Exposure / audience:** `local-only` — **CONFIRMED** (grep across `*.py/*.sh/*.ino/*.h`: zero sockets/binds/listeners). reachable by: any local process with OS permission on the serial tty and the data files.
- **Security mechanisms (in place):** defensive parsing — `decode(errors='ignore')`, length checks, `try/except` on `int()` (bad lines skipped); `software/.gitignore` excludes `data/`.
- **Known gaps / findings:**
  - `medium` — **dependencies unpinned, no hashes, no lockfile** (`>=` lower bounds) ⇒ dependency-confusion / typosquat / version-drift; builds not reproducible. Pin exact versions + hashes (`pip-compile --generate-hashes`) and add `pip-audit`/Dependabot. *(CONFIRMED)*
  - `low` — **path traversal via `--label`**: `f'{outdir}/{label}.csv'` is unsanitized, so a crafted label can write outside `outdir`. Local operator-supplied arg (low), but add a basename/whitelist guard. *(CONFIRMED)*
  - `low` — **host tools trust any device on the port**; no device-identity check. Pin expected USB VID/PID (`serial.tools.list_ports`) or a firmware identity handshake. *(CONFIRMED)*
  - `info` — `numpy.genfromtxt` trusts device-fed CSV shape; future model persistence must avoid untrusted `pickle`. *(self-assessed)*
- **Test cadence:** automated dependency + toolchain scan on **every dependency change** and **weekly**; a **one-time hardening pass now** (hash-locked lockfile, pin OpenSCAD/core, add the traversal guard); **quarterly** manual supply-chain review + after any major bump.
- **Criticality:** medium · **Test cost:** low
- **Last reviewed:** 2026-07-04 · **Last assessed:** 2026-07-04 (workflow + manual)

---

## 4. Data / Privacy

### EMG biometric data
- **Classification:** data / privacy
- **Technology:** CSV telemetry (`millis,emg_raw,emg_env,state,servo_pos,servo_load,jammed`).
- **Hosting:** local files under `software/data/` (**gitignored**).
- **Authentication:** OS file permissions only.
- **Exposure / audience:** `local-only`; **not committed** to git (CONFIRMED). Any local process with read access can read the unencrypted traces.
- **Security mechanisms (in place):** `.gitignore` keeps `data/` out of git history.
- **Known gaps / findings:**
  - `medium` — **plaintext biometric (EMG) at rest**: no encryption, access control, or retention policy. Surface-EMG is biometric/health-adjacent (GDPR special-category; HIPAA-adjacent clinically). Encrypt at rest (or encrypted volume), define retention/erasure, and require consent **before any real-subject collection**. *(CONFIRMED — design-level)*
  - `info` — keep `software/.gitignore`'s `data/` rule intact; verify on changes to avoid accidental commit. *(self-assessed)*
- **Test cadence:** privacy/DPIA review **before any real-subject collection**; verify `.gitignore` on **every change under `software/`**; revisit encryption/retention when data leaves the dev machine.
- **Criticality:** low now / high if real users · **Test cost:** low
- **Last reviewed:** 2026-07-04 · **Last assessed:** 2026-07-04 (workflow + manual)

---

## Placeholders — categories with no evidenced members yet
_Fill these in as systems come into scope. Empty ≠ safe; empty = not yet inventoried._

- **Cloud hosts / compute (AWS, GCP, Azure, VPS, containers/k8s):** — none recorded yet
- **Domains / sites / web properties:** — none recorded yet
- **Databases (SQL, NoSQL, caches, object stores):** — none recorded yet
- **First-party APIs / services:** — none recorded yet
- **SaaS / third-party vendors:** GitHub (see §1); others — none recorded yet
- **Identity / OAuth / SSO providers:** — none recorded yet
- **Networks / VPN / remote access:** — none recorded yet
- **CI/CD & build infrastructure:** none configured in-repo (no `.github/`) — none recorded yet
- **Secrets management (vaults, KMS):** — none recorded yet

---

## How to use this file
- **Answer "what's our attack surface for X?"** → find X's entry (or note it's uninventoried).
- **Add a system** → follow the `attack-surface` skill's entry schema.
- **(Re)assess** → run `AssessAttackSurface` and fold verified findings + cadence back in.

## Maintenance log
| Date | Change | Trigger |
|---|---|---|
| 2026-07-04 | Initial inventory: 4 evidenced surfaces + external-category placeholders. | attack-surface skill bootstrap |
| 2026-07-04 | Folded in `AssessAttackSurface` results (83-agent run) + manual cross-check: verified exposures (all physical/local-only), secret-clean history, plaintext-HTTP remote, servo-bus trust, no secure boot, no auth tiers, unpinned deps/toolchain, `--label` path traversal, plaintext biometric at rest; set per-surface cadences. **Fixed** the blocking-serial-read safety-loop stall in firmware. | assessment |

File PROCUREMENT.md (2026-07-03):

# Phase 0 — Procurement & Setup Checklist

Work through this before Phase 1. Prices approximate (mid-2026, single-unit
retail); see `hardware-research.md` for alternatives and "pick this if..."
guidance. This is the **starter (~$150)** order that gets you through Phase 1–2.

## A. Order — starter BOM
| ✓ | Item | Suggested part | Qty | ~Price | Notes |
|---|---|---|---|---|---|
| ☐ | Main servo | Feetech STS3215 (serial bus) | 1 | $20 | position + load feedback |
| ☐ | Microcontroller | ESP32-S3 DevKitC (or XIAO ESP32-S3) | 1 | $12 | |
| ☐ | Bus adapter | Waveshare Bus Servo Adapter | 1 | $6 | OR a 1 kΩ resistor (free) |
| ☐ | Buck converter | 12→5 V, 3 A | 1 | $4 | powers MyoWare/logic |
| ☐ | TPU filament | eSUN / Overture TPU 95A, 1 kg | 1 | $22 | fingers |
| ☐ | PETG filament | any brand, 1 kg | 1 | $20 | palm/rockers/wrist (may have on hand) |
| ☐ | Tendon line | KastKing/PowerPro UHMWPE 65–80 lb | 1 | $15 | |
| ☐ | PTFE liner | Capricorn 2×1 mm, 1 m | 1 | $10 | route at every bend |
| ☐ | Fingertip silicone | Ecoflex 00-30 trial unit | 1 | $45 | casts many pads |
| ☐ | Fasteners kit | M3 screws/nuts/grub + heat-set inserts | 1 | $12 | |
| ☐ | 2S Li-ion pack + BMS | 7.4 V, ≥5 A | 1 | (have/Phase 2) | can bench-power first |
| | **Starter subtotal** | | | **~$166** | |

## B. Order — Phase 3+ add-ons (defer until Phase 1–2 pass)
| ✓ | Item | Part | ~Price |
|---|---|---|---|
| ☐ | EMG sensor | MyoWare 2.0 + cable/electrode shield | $50 |
| ☐ | Electrodes | disposable gel pads (30-pack) | $10 |
| ☐ | Vacuum pump | 12 V mini diaphragm | $22 |
| ☐ | 3-way solenoid + check valve | 6–12 V | $15 |
| ☐ | 2× MOSFET modules | logic-level N-FET + flyback | $8 |
| ☐ | Latex balloons + ground coffee | jamming media | $8 |

## C. Consumables you likely already have
- Kitchen scale (fingertip-force test), calipers, multimeter
- Soldering iron (also sets heat-set inserts), heat-shrink
- Fishing-line crimps + pliers (or practice the Palomar knot)

## D. Toolchain setup
| ✓ | Tool | Purpose | Verify |
|---|---|---|---|
| ☐ | OpenSCAD | render CAD → STL | `openscad --version` |
| ☐ | Slicer (Cura / PrusaSlicer / OrcaSlicer) | STL → G-code | opens `build/stl/*.stl` |
| ☐ | Arduino IDE + ESP32 board package | flash firmware | compiles `firmware/prosthetic_hand` |
| ☐ | Python 3.11+ + `software/requirements.txt` | EMG pipeline | `python emg_train.py --selftest` |
| ☐ | Filament dryer / dry box | TPU must be dry | — |

### Toolchain notes
- **Firmware compile**: install the ESP32 Arduino core, select board
  "ESP32S3 Dev Module". No external libraries needed — the STS3215 driver is
  the bundled `sts_servo.h`.
- **Python**: `pip install -r software/requirements.txt`, then
  `python software/emg_train.py --selftest` should print a confusion matrix.
- **STLs are pre-rendered** in `build/stl/` — you can slice immediately even
  before installing OpenSCAD; OpenSCAD is only needed to change parameters.

## Phase 0 exit criteria
- [ ] All starter-BOM parts on hand
- [ ] TPU dried (6–8 h @ 55 °C or in a dry box)
- [ ] Slicer opens the STLs; firmware compiles; `emg_train.py --selftest` passes

Once all three hold, proceed to `ROADMAP.md` Phase 1 and `build/README.md`.

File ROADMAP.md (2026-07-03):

# Flexible Prosthetic Hand — Development Roadmap

Project docs:
- `prosthetic-hand-design.md` — design philosophy & concept directions
- `finray-cad-print-parameters.md` — fin-ray geometry & print settings
- `hardware-research.md` — component research & BOMs
- `architecture.md` — system architecture (this roadmap's technical companion)
- `cad/` — parametric OpenSCAD models
- `firmware/` — ESP32-S3 control firmware
- `software/` — EMG data collection & training pipeline

## Phase 0 — Procurement & setup (week 0)
See `PROCUREMENT.md` for the full checklist.
- [x] Toolchain: OpenSCAD installed; all CAD renders to manifold STLs
      (`cad/render_all.sh`); Python EMG pipeline passes `--selftest`
- [x] Pre-rendered STLs provided in `build/stl/` so slicing needs no CAD tool
- [ ] Order the ~$166 starter BOM (`PROCUREMENT.md` §A) — *physical, user*
- [ ] Dry-box or filament dryer for TPU — *physical, user*
- [ ] Confirm slicer opens `build/stl/*.stl`; Arduino IDE compiles firmware

**Exit criteria:** all parts on hand, TPU dried, toolchain compiles the firmware.
*(Toolchain + design side complete; procurement/drying are physical steps.)*

## Phase 1 — Single finger (weeks 1–2)
- [x] Fin-ray geometry designed, rendered, and visually verified (side
      profile shows correct two-wall + diagonal-rib truss) — `build/png/`
- [x] Flow-calibration coupon modeled + rendered (`cad/calibration_coupon.scad`)
- [x] Three finger variants exported: baseline, floating-rib, graded-wall
      (`build/stl/finger_{index,floating,graded}.stl`)
- [ ] Print the coupon; tune flow to 1.0 mm ±0.05 (T1) — *physical, user*
- [ ] Bench test: push mid-finger, verify tip wraps toward contact (T2)
- [ ] Add tendon + PTFE liner, measure fingertip force 5–15 N (T3)
- [ ] 500-cycle flex test; inspect rib junctions (T4)

**Exit criteria:** one variant selected; ≥5 N fingertip force; no cracks at 500 cycles.
*(Design/export complete; the print-and-measure loop is physical — run
`docs/test-protocol.md` T1–T4.)*

## Phase 2 — Hand assembly, single servo (weeks 3–4)
- [ ] Print 4 fingers (80/88/82/65 mm) + thumb + palm + whiffle-tree
      (`cad/whiffletree.scad`)
- [ ] Route tendons through PTFE; re-tensionable anchor screws (UHMWPE creeps)
- [ ] Wire STS3215 to ESP32-S3 (`firmware/README.md` wiring table)
- [ ] Flash `firmware/prosthetic_hand/` — serial-command mode first (no EMG)
- [ ] Grasp test set: egg, 500 ml bottle, pen, paper sheet, apple

**Exit criteria:** 4/5 grasp-set objects held for 30 s at ≤60 % servo load.

## Phase 3 — EMG control (weeks 5–6)
- [ ] Add MyoWare 2.0 on forearm flexor; verify envelope signal in serial plotter
- [ ] Enable EMG mode in firmware: dual-threshold hysteresis → open/close
- [ ] Proportional mode: EMG amplitude → grip effort
- [ ] Collect training data with `software/emg_collect.py`; train classifier
      with `software/emg_train.py` (rest / close / open via co-contraction)

**Exit criteria:** user opens/closes hand reliably (>90 % of attempts) wearing
the sensor, 10-minute session without recalibration.

## Phase 4 — Variable stiffness (weeks 7–9)
- [ ] Build jamming pad (latex + coffee grounds) into palm
- [ ] Plumb pump + 3-way solenoid; MOSFET drivers on ESP32 pins
- [ ] Firmware: auto-stiffen when servo load exceeds threshold (heavy carry),
      vent on release
- [ ] Compare grasp-set performance jammed vs unjammed

**Exit criteria:** hand carries a 2 kg bag handle jammed; same hand handles an
egg unjammed, with no manual mode switch.

## Phase 5 — Iterate toward wearable (weeks 10+)
- [ ] Socket/wrist interface (study exiii HACKberry, e-NABLE patterns)
- [ ] Battery + BMS integration, power budget validation (`architecture.md` §6)
- [ ] Weight pass: target <450 g distal of wrist
- [ ] Upgrade path: Dynamixel XL330 current control, varioShore graded fingers,
      2–3 channel BioAmp EMG + on-device TinyML

## Risks & mitigations
| Risk | Mitigation |
|---|---|
| Tendon creep loosens grip over days | Re-tensionable anchor screws (Phase 2) |
| TPU delamination at ribs | Print orientation rule + 500-cycle gate (Phase 1) |
| EMG drift between sessions | Auto-calibration routine at startup (firmware) |
| Jamming membrane puncture | Spare balloons; latex sheet upgrade in Phase 5 |
| Servo overheating on sustained grip | Load-based duty limiting in firmware |

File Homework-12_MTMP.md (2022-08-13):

# Python Practice - Session 12

### Task 12.1
Implement the [dining philosophers problem](https://en.wikipedia.org/wiki/Dining_philosophers_problem).

### Optional
Try different synchronization primitives and fix deadlock in [dining philosophers problem](https://en.wikipedia.org/wiki/Dining_philosophers_problem).

### Materials
* [Concurrency and parallelism in python](https://www.toptal.com/python/beginners-guide-to-concurrency-and-parallelism-in-python)
* [Multiprocessing](https://zetcode.com/python/multiprocessing/)
* [GIL](https://tproger.ru/translations/global-interpreter-lock-guide/)
* [Python Gil](https://realpython.com/python-gil/)

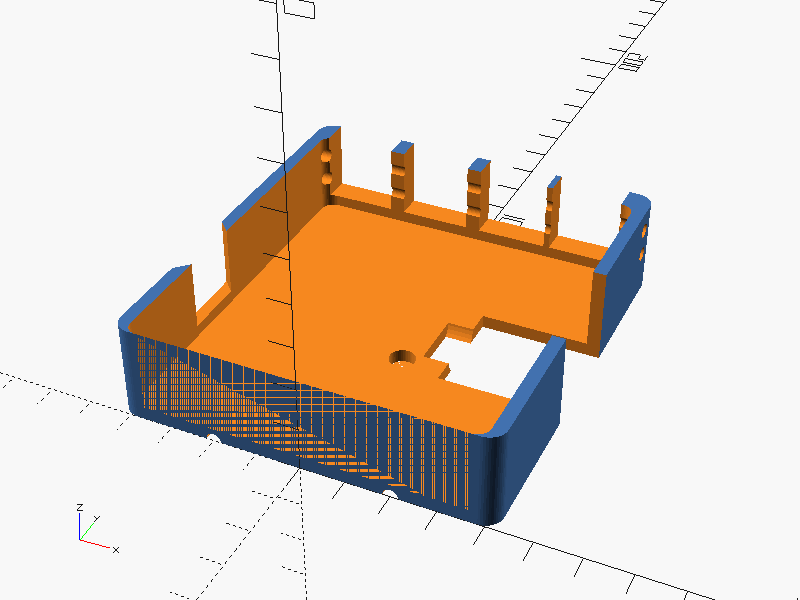
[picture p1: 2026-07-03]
build/png/palm_chassis.png

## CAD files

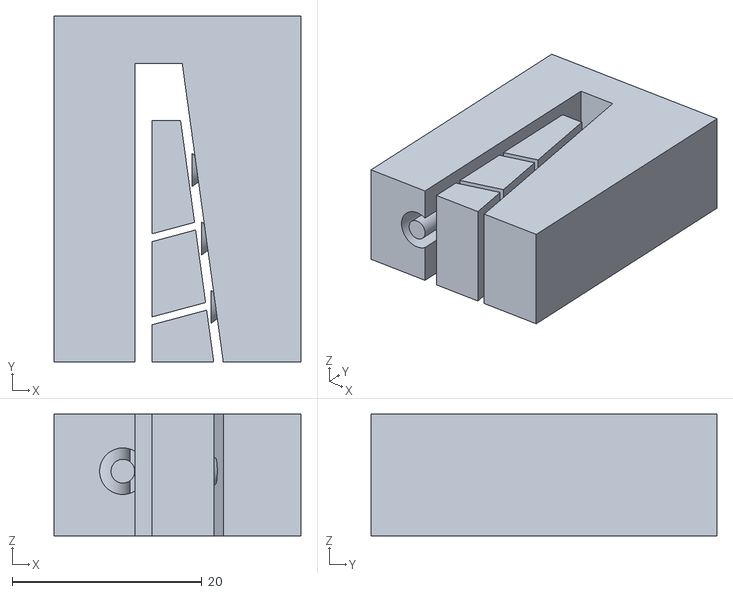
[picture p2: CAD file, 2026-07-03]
build/stl/fingertip_pad_mold.stl
26.0 x 36.4 x 12.8

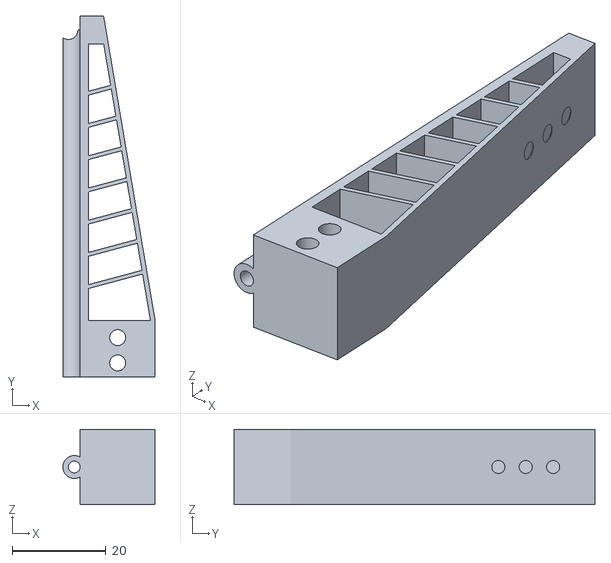
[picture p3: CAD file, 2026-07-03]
build/stl/finger_pinky.stl
19.7 x 77.0 x 16.0

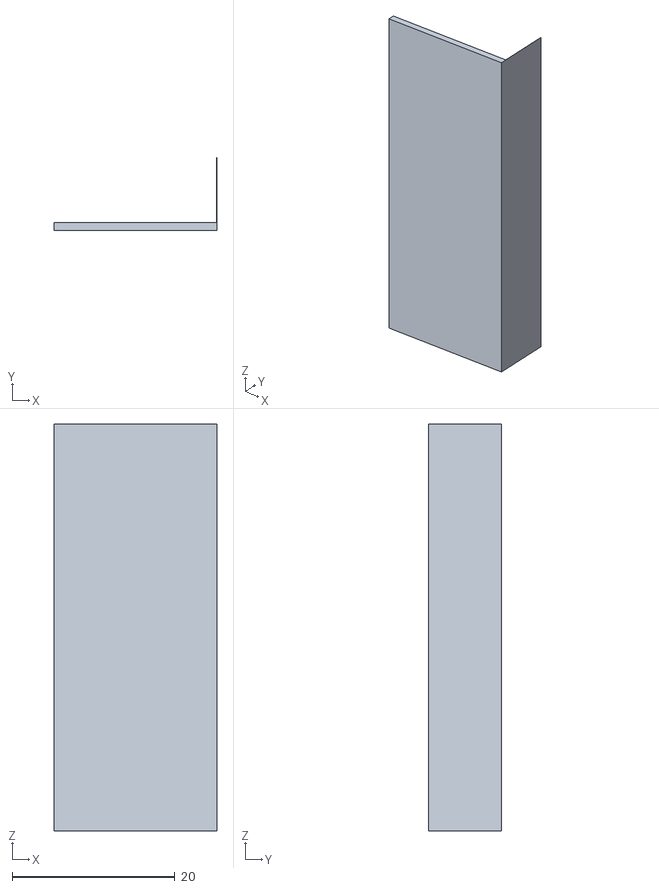
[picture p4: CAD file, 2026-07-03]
build/stl/calibration_coupon.stl
20.0 x 9.00 x 50.0

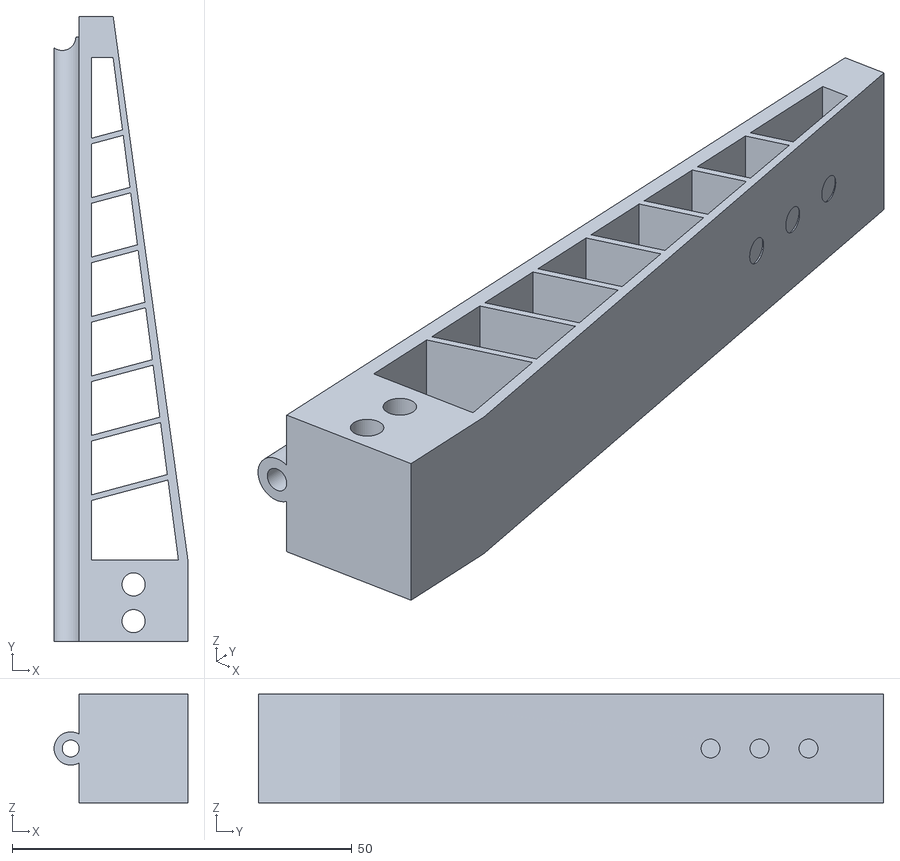
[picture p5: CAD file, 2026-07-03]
build/stl/finger_graded.stl
19.7 x 92.0 x 16.0

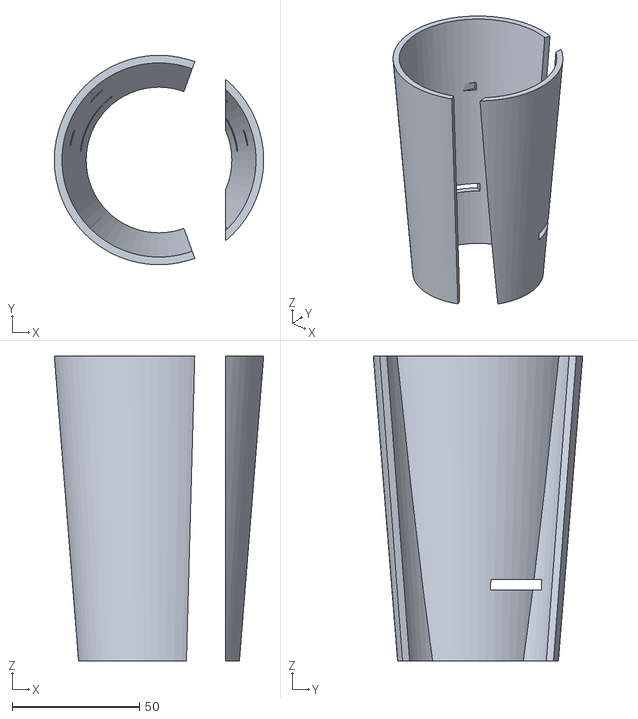
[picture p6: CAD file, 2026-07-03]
build/stl/socket_cuff.stl
82.4 x 82.4 x 120.0

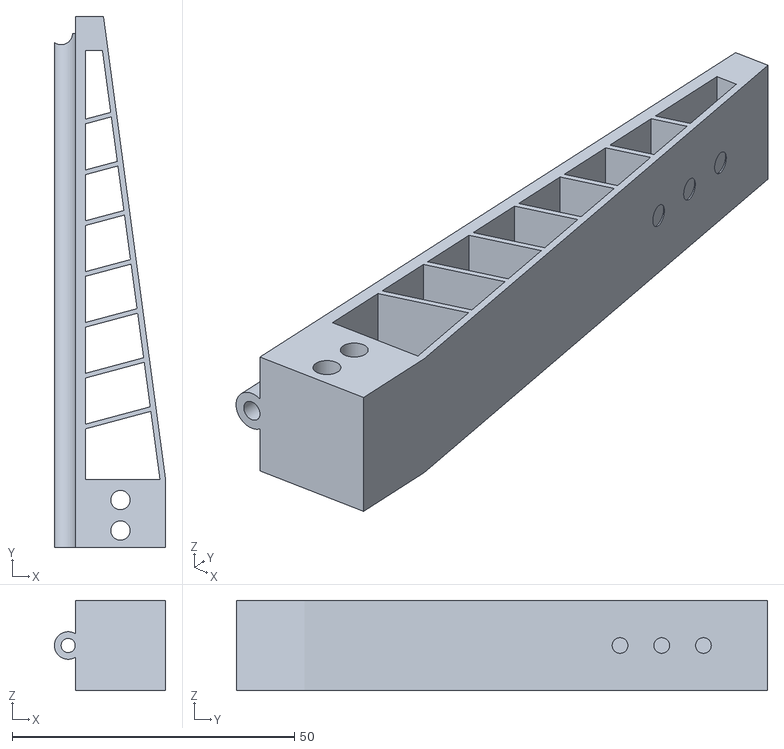
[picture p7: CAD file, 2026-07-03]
build/stl/finger_ring.stl
19.7 x 94.0 x 16.0

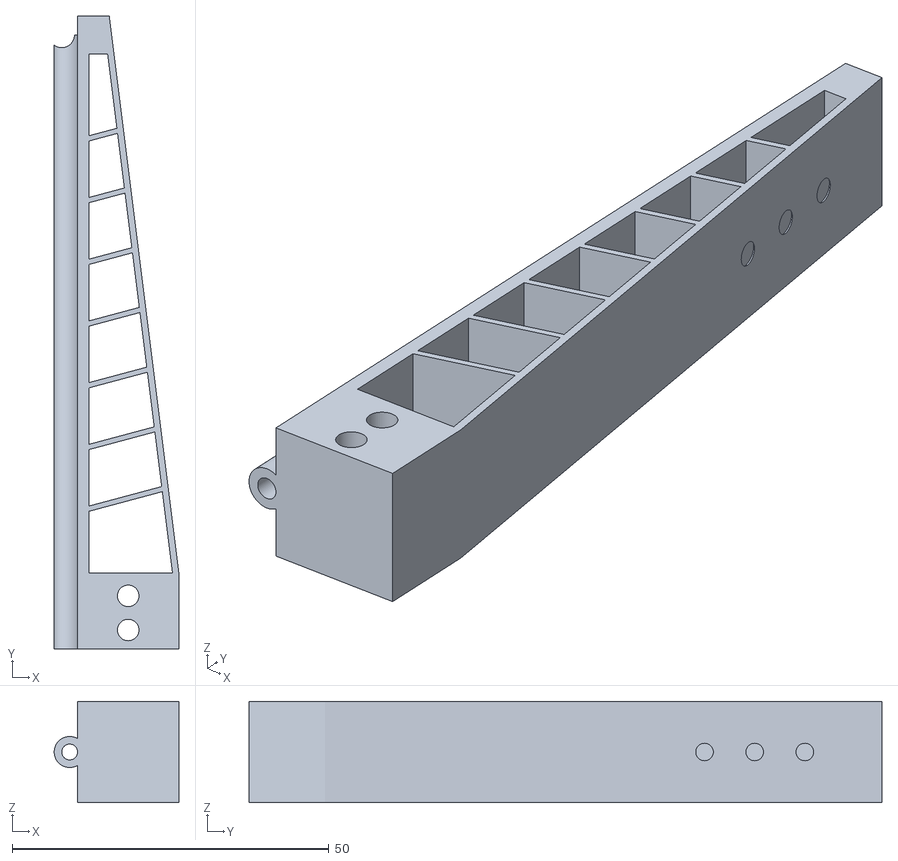
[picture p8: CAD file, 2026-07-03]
build/stl/finger_middle.stl
19.7 x 100.0 x 16.0

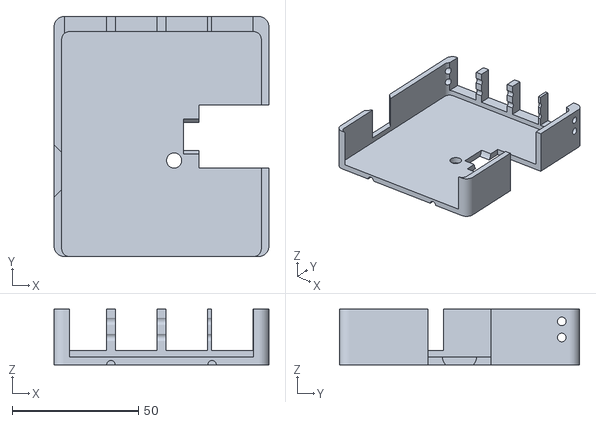
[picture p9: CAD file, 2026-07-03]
build/stl/palm_chassis.stl
85.0 x 95.0 x 22.0

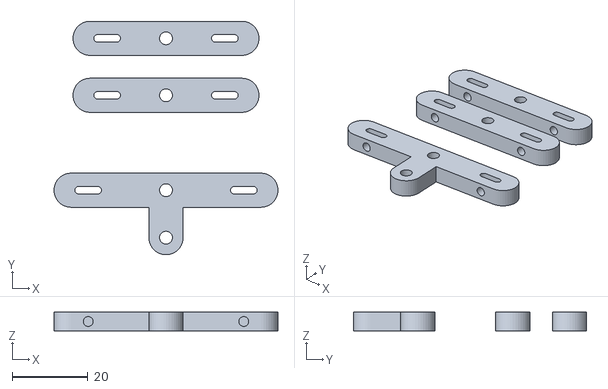
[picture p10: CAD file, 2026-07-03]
build/stl/whiffletree.stl
59.0 x 61.5 x 5.00

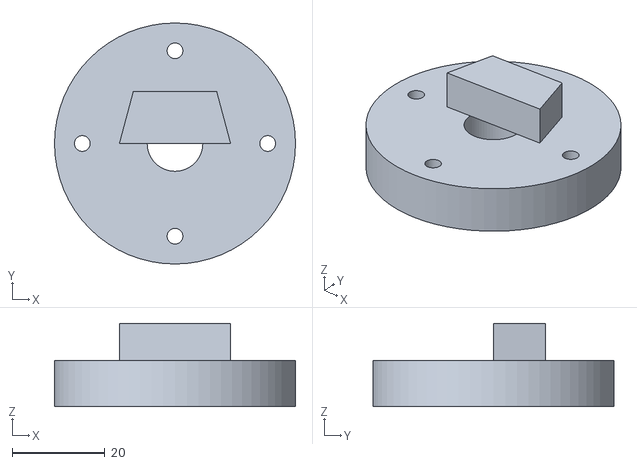
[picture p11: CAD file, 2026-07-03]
build/stl/wrist_adapter.stl
52.0 x 52.0 x 18.0

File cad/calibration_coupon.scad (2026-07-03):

// ============================================================
// TPU flow-calibration coupon (Phase 1, test T1).
// A single-wall rectangle: print it, measure the wall with
// calipers at 5 points, adjust slicer flow % until measured =
// designed (wall_t) +/- 0.05 mm. Print lying flat, same settings
// as the fingers.
// ============================================================

wall_t   = 1.0;   // target wall thickness (match front_wall_t you'll use)
height   = 50;    // Z
length   = 20;    // X footprint
$fn = 8;
EPS = 0.01;

difference() {
    cube([length, wall_t + 8, height]);
    // hollow it into a thin U-wall so only the target wall is printed
    translate([-EPS, wall_t, -EPS])
        cube([length - 2*EPS, 8 + EPS, height + 2*EPS]);
}
// engrave the target thickness so coupons don't get mixed up
translate([2, wall_t/2, height - 6])
    rotate([90, 0, 0])
        linear_extrude(wall_t + EPS, center = true)
            text(str(wall_t), size = 5);

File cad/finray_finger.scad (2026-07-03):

// ============================================================
// Parametric fin-ray finger for tendon-driven prosthetic hand
// See ../finray-cad-print-parameters.md for parameter guidance.
//
// Coordinate system (side profile in XY, extruded along Z):
//   X = depth (back wall at x=0, front/contact wall converging)
//   Y = length (base at y=0, tip at y=finger_length)
//   Z = finger width
//
// PRINT ORIENTATION: lying on its side face (as modeled) — walls
// and ribs are continuous XY extrusion paths; bending stress runs
// along layer lines. TPU 95A, 2 perimeters, 0-10% infill.
// ============================================================

/* [Finger size] */
finger_length = 80;      // base->tip. index/middle/ring/pinky ~ 80/88/82/65
base_depth    = 16;      // wall-to-wall at the base
tip_depth     = 5;       // wall-to-wall at the tip
finger_width  = 16;      // extrusion width (Z)

/* [Walls] */
front_wall_t      = 1.0; // dominant compliance knob (0.8 soft .. 1.6 firm)
front_wall_t_tip  = 1.0; // set < front_wall_t for a graded ("biological") wall
back_wall_t       = 1.8; // keep >= 1.5x front wall

/* [Ribs] */
rib_count    = 7;
rib_t        = 0.8;
rib_tilt     = 15;       // deg toward tip; 0 = perpendicular to back wall
floating_gap = 0;        // 0.4 => "floating ribs" (soft first contact, then stiffen)

/* [Tendon] */
tendon_channel_d = 2.5;  // fits 2mm-OD PTFE liner
tendon_anchor_d  = 4;    // cross-hole near tip, figure-8 stopper knot behind it

/* [Base mount] */
base_height   = 12;      // mounting block below y=0
mount_hole_d  = 3.4;     // M3 clearance, two cross-holes
tip_solid_len = 6;       // solid tip cap

$fn = 48;
EPS = 0.01;

// ---- derived ----
// front wall outer x at height y (linear taper base->tip)
function fw_outer(y) = base_depth - (base_depth - tip_depth) * y / finger_length;
// graded front wall thickness at height y
function fw_t(y) = front_wall_t - (front_wall_t - front_wall_t_tip) * y / finger_length;
function fw_inner(y) = fw_outer(y) - fw_t(y);

// ------------------------------------------------------------
// 2D profile pieces
// ------------------------------------------------------------
N = 24; // taper segmentation

module envelope_2d() { // full outer boundary of the profile
    polygon(concat(
        [[0, 0]],
        [for (i = [0:N]) [fw_outer(i * finger_length / N), i * finger_length / N]],
        [[0, finger_length]]
    ));
}

module cavity_2d() { // interior air: inside walls, minus floating gap strip
    polygon(concat(
        [[back_wall_t, 0]],
        [for (i = [0:N]) let (y = i * finger_length / N)
            [max(back_wall_t + EPS, fw_inner(y) - floating_gap), y]],
        [[back_wall_t, finger_length]]
    ));
}

module ribs_2d() { // overlong tilted ribs, trimmed against the cavity
    intersection() {
        cavity_2d();
        for (i = [1:rib_count]) {
            y = i * (finger_length - tip_solid_len - 4) / (rib_count + 1);
            translate([back_wall_t - EPS, y])
                rotate(rib_tilt)
                    square([base_depth * 1.5, rib_t]);
        }
    }
}

module profile_2d() {
    union() {
        difference() { // walls + solid tip
            envelope_2d();
            // subtract cavity everywhere except the solid tip cap
            intersection() {
                cavity_2d();
                translate([-EPS, -EPS])
                    square([base_depth + 2 * EPS,
                            finger_length - tip_solid_len + EPS]);
            }
        }
        ribs_2d();
        // base mounting block
        translate([0, -base_height]) square([base_depth, base_height + EPS]);
    }
}

// ------------------------------------------------------------
// 3D finger
// ------------------------------------------------------------
module finray_finger() {
    difference() {
        union() {
            linear_extrude(finger_width) profile_2d();
            // thickened ridge on the back wall to house the tendon channel
            translate([-tendon_channel_d / 2, -base_height, finger_width / 2])
                rotate([-90, 0, 0])
                    cylinder(d = tendon_channel_d + 2 * 1.2,
                             h = finger_length - tip_solid_len / 2 + base_height);
        }
        // tendon channel bore (along the back wall, full length)
        translate([-tendon_channel_d / 2, -base_height - EPS, finger_width / 2])
            rotate([-90, 0, 0])
                cylinder(d = tendon_channel_d,
                         h = finger_length + base_height + 2 * EPS);
        // tendon anchor cross-hole in the solid tip
        translate([-tendon_channel_d, finger_length - tip_solid_len / 2, -EPS])
            cylinder(d = tendon_anchor_d, h = finger_width + 2 * EPS);
        // M3 mounting cross-holes in the base block
        for (y = [-base_height * 0.3, -base_height * 0.75])
            translate([base_depth / 2, y, -EPS])
                cylinder(d = mount_hole_d, h = finger_width + 2 * EPS);
        // silicone-pad dovetail keys on the distal third of the contact wall
        for (i = [0:2]) {
            y = finger_length * (0.68 + i * 0.09);
            translate([fw_inner(y) + fw_t(y) / 2, y, finger_width / 2])
                rotate([0, 90, 0])
                    cylinder(d1 = 3.5, d2 = 2, h = fw_t(y) + EPS, center = false);
        }
    }
}

// ------------------------------------------------------------
// Optional: open-face drape mold for the silicone fingertip pad.
// Print in PLA, pour Ecoflex 00-30 ~3.5mm deep, press finger tip in.
// ------------------------------------------------------------
module fingertip_pad_mold(pad_t = 3.5) {
    pad_len = finger_length * 0.33;
    difference() {
        cube([base_depth + 10, pad_len + 10, finger_width * 0.8]);
        translate([5 + pad_t, 5 - (finger_length - pad_len), finger_width * 0.8
                   - finger_width + 2])
            finray_finger();
    }
}

// ---- render selection ----
part = "finger"; // "finger" | "mold"
if (part == "finger") finray_finger();
else fingertip_pad_mold();

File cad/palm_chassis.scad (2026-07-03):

// ============================================================
// Palm / chassis — mounts 4 fingers + thumb, houses the servo,
// whiffle-tree differential, tendon routing, and the jamming pad.
//
// PRINT: PETG or PLA+, 4 perimeters, 30% gyroid, flat (palm-down).
// Fingers bolt to the finger rail with M3; the STS3215 drops into
// the servo pocket; the jamming pad seats in the palm recess.
//
// See ../architecture.md §2 for the mechanical layout.
// ============================================================

/* [Palm size] */
palm_w      = 85;   // across the knuckles
palm_len    = 95;   // wrist to knuckle line
palm_t      = 22;   // thickness (houses servo + routing)
wall        = 3;

/* [Finger mounts] — x offset of each finger centerline from palm center */
// index / middle / ring / pinky spacing across an 85 mm palm
finger_x    = [-30, -10, 10, 28];
finger_w    = 16;   // must match finray_finger.scad finger_width
mount_hole_d = 3.4; // M3 clearance, matches base cross-holes

/* [Thumb] */
thumb_oppose_deg = 45;
thumb_x = -38; thumb_y = 28;

/* [Servo pocket] — Feetech STS3215: 45.2 x 24.7 x 35 mm */
servo_l = 45.6; servo_w = 25.1; servo_h = 35.4;

/* [Jamming pad recess] */
pad_recess_d = 45; pad_recess_depth = 8;

/* [Wrist interface] — bolt circle shared with wrist_socket.scad */
wrist_bolt_circle = 40; wrist_bolt_d = 3.4; wrist_bolt_n = 4;

$fn = 48;
EPS = 0.01;

module rounded_box(w, l, h, r = 4) {
    hull() for (x = [r - w/2, w/2 - r], y = [r, l - r])
        translate([x, y, 0]) cylinder(r = r, h = h);
}

module finger_mount_negative(x) {
    // slot the finger base sits in + two cross-holes for M3
    translate([x, palm_len - EPS, palm_t - finger_w]) {
        translate([-finger_w/2 - 0.3, -14, -0.3])
            cube([finger_w + 0.6, 15, finger_w + 0.6]);   // base pocket
        for (z = [finger_w * 0.3, finger_w * 0.7])
            translate([-palm_w, -7, z])
                rotate([0, 90, 0]) cylinder(d = mount_hole_d, h = palm_w * 2);
        translate([0, -7, finger_w/2])                     // tendon exit
            rotate([90, 0, 0]) cylinder(d = 4, h = 20);
    }
}

module palm_chassis() {
    difference() {
        rounded_box(palm_w, palm_len, palm_t);

        // hollow interior for routing + differential
        translate([0, 0, wall])
            rounded_box(palm_w - 2*wall, palm_len - 2*wall, palm_t, 3);

        // servo pocket (drops in from the palm side, wires exit to wrist)
        translate([servo_l/2 - 8, palm_len/2 - servo_w/2, palm_t - servo_h])
            cube([servo_l, servo_w, servo_h + EPS]);
        translate([servo_l/2 - 8, palm_len/2 - servo_w/2, palm_t - servo_h])
            translate([-6, servo_w/2, servo_h/2])          // horn/cable slot
                rotate([0, 90, 0]) cylinder(d = 14, h = servo_l + 12);

        // finger mounts
        for (x = finger_x) finger_mount_negative(x);

        // thumb mount (rotated post)
        translate([thumb_x, thumb_y, palm_t - finger_w])
            rotate([0, 0, thumb_oppose_deg])
                translate([-finger_w/2 - 0.3, 0, -0.3])
                    cube([finger_w + 0.6, 15, finger_w + 0.6]);

        // jamming pad recess in the palm face
        translate([5, palm_len * 0.4, palm_t - pad_recess_depth])
            cylinder(d = pad_recess_d, h = pad_recess_depth + EPS);
        translate([5, palm_len * 0.4, 0])                  // pad tube pass-through
            cylinder(d = 6, h = palm_t);

        // wrist bolt circle at the proximal face
        for (i = [0:wrist_bolt_n - 1])
            rotate([0, 0, i * 360/wrist_bolt_n])
                translate([wrist_bolt_circle/2, 0, -EPS])
                    translate([0, 3, 0])
                        rotate([90, 0, 0])
                            cylinder(d = wrist_bolt_d, h = 8);
    }
}

palm_chassis();

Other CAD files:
build/stl/finger_index.stl
build/stl/finger_floating.stl
cad/whiffletree.scad
cad/wrist_socket.scad

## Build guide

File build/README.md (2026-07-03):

# Build — pre-rendered print files (Phase 1)

STL files rendered from the parametric `../cad/*.scad` models, ready to slice.
Regenerate any of them with `../cad/render_all.sh` after editing parameters.

## Validation status
All parts rendered with OpenSCAD 2021.01 and report **`Simple: yes`** — i.e.
closed, manifold, 2-manifold solids with no self-intersections, which is what
a slicer requires. (Re-verify with `render_all.sh`, which fails loudly on any
non-simple result.)

| STL | Rendered | Manifold | Vertices (approx) |
|---|---|---|---|
| `finger_index.stl` (80 mm) | ✓ | ✓ | 925 |
| `finger_middle.stl` (88 mm) | ✓ | ✓ | ~930 |
| `finger_ring.stl` (82 mm) | ✓ | ✓ | ~930 |
| `finger_pinky.stl` (65 mm) | ✓ | ✓ | ~900 |
| `finger_floating.stl` (variant) | ✓ | ✓ | ~925 |
| `finger_graded.stl` (variant) | ✓ | ✓ | ~940 |
| `calibration_coupon.stl` | ✓ | ✓ | — |
| `fingertip_pad_mold.stl` | ✓ | ✓ | — |
| `whiffletree.stl` | ✓ | ✓ | — |
| `palm_chassis.stl` | ✓ | ✓ | — |
| `wrist_adapter.stl` | ✓ | ✓ | — |
| `socket_cuff.stl` | ✓ | ✓ | — |

Preview images are in `png/`.

## Phase 1 print order (see ../ROADMAP.md)
Print in this sequence; don't print all fingers until the coupon + one finger pass.

### 1. `calibration_coupon.stl` — FIRST
TPU 95A, your finger settings. Measure the wall at 5 points; adjust flow %
until measured = 1.0 mm ±0.05. (Test T1 in `../docs/test-protocol.md`.)

### 2. One finger variant, then bench-test before committing
Print `finger_index.stl` (baseline), `finger_floating.stl`, and
`finger_graded.stl`. Run tests T2–T4; pick the winner.

### 3. Remaining fingers in the chosen variant
`finger_middle/ring/pinky.stl`. Thumb = reprint `finger_index.stl`.

## Slicer settings by part
| Part(s) | Material | Layer | Walls | Infill | Orientation | Supports |
|---|---|---|---|---|---|---|
| fingers, coupon | TPU 95A | 0.20 mm | 2 | 0–10 % | **lying on side face (as exported)** | none |
| pad mold | PLA | 0.12 mm | 3 | 15 % | cavity up | none |
| whiffletree | PETG/PLA+ | 0.20 mm | 4 | 30 % gyroid | flat | none |
| palm_chassis | PETG/PLA+ | 0.20 mm | 4 | 30 % gyroid | palm-down | on servo pocket overhang |
| wrist_adapter | PETG | 0.20 mm | 4 | 30 % | dovetail up | none |
| socket_cuff | TPU 95A | 0.24 mm | 3 | 0 % | axis vertical | none |

TPU specifics (temps, retraction, drying) are in
`../finray-cad-print-parameters.md` §2. **Dry the TPU first** — it matters more
than any slicer setting.

## Estimated print times / material (0.4 mm nozzle, ~30 mm/s TPU)
| Part | Time | Material |
|---|---|---|
| calibration coupon | ~15 min | ~2 g |
| one finger | ~1.5 h | ~12 g |
| full finger set (5) | ~7.5 h | ~60 g |
| whiffletree plate | ~1 h | ~15 g |
| palm chassis | ~5 h | ~90 g |
| wrist adapter | ~1 h | ~25 g |
| socket cuff | ~4 h | ~70 g |

(Times are rough; a fast CoreXY roughly halves them.)

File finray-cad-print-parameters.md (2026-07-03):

# Fin-Ray Finger — CAD & 3D-Print Parameters

Companion to `prosthetic-hand-design.md`. Everything here targets a standard
FDM printer with a 0.4 mm nozzle and TPU 95A filament.

## 1. Fin-ray geometry (the parameters that matter)

A fin-ray finger is two converging walls joined by internal ribs. When the
front (contact) wall is pushed, the rib truss makes the tip curl *toward* the
object instead of away — that's the passive wrapping behavior.

```
        tip
        /|
       / |
      /  |   <- back wall (thicker, stiffer)
ribs /---|
    /----|
   /-----|
  /______|
  base (mounts to palm / tendon anchor)
```

### Recommended starting dimensions (adult index finger scale)

| Parameter | Value | Effect when you change it |
|---|---|---|
| Finger length (base→tip) | 80 mm | Match to hand anthropometry (index ≈ 70–90 mm) |
| Base depth (wall-to-wall) | 16 mm | Deeper base = higher grip force, less conformity |
| Tip depth | 4–6 mm | Sharper tip wraps small objects better |
| Finger width | 15–18 mm | Wider = more contact area, stiffer in torsion |
| Front (contact) wall thickness | 1.0 mm | Dominant compliance knob. 0.8 = very soft, 1.6 = firm |
| Back wall thickness | 1.6–2.0 mm | Keep ≥1.5× front wall so bending concentrates at the contact side |
| Rib thickness | 0.8 mm | Thicker ribs resist wrap; keep ≤ front wall |
| Rib count | 6–8 | More ribs = smoother curvature, slightly stiffer |
| Rib spacing | 8–10 mm | Even spacing; last rib ≥5 mm from tip |
| Rib angle | 90° to back wall, or tilted 10–20° toward tip | Tilting toward the tip increases wrap depth |
| Rib–wall junction fillet | 0.5–1 mm | Prevents stress cracking at layer lines |

### Two high-leverage variants
- **Floating ribs**: leave a 0.3–0.5 mm gap between rib ends and the front
  wall. The finger is very soft on first contact, then stiffens as ribs
  engage — a free, passive version of "soft by default, stiff on demand."
- **Graded walls**: taper the front wall from 1.4 mm at the base to 0.8 mm at
  the tip. Mimics the proximal-to-distal stiffness gradient of a human finger.

### Tendon integration (for the actuated version)
- Run a 2.5 mm diameter tendon channel along the *back* wall, exiting at the
  base. Pulling the tendon pre-curls the finger; contact then triggers the
  fin-ray wrap. Line the channel with PTFE tube (2 mm ID) to cut friction.
- Tendon anchor: a 4 mm cross-hole near the tip; knot a figure-8 stopper knot
  behind it.

### CAD approach
Model it parametrically so every value above is a named variable:
- **Fusion 360 / Onshape**: single sketch of the side profile (two walls +
  ribs as a sketch pattern), extrude to finger width. Drive everything from
  a parameters table.
- **OpenSCAD**: ideal here — the whole finger is ~40 lines with `for` loops
  for ribs, and you can regenerate a full 4-finger set with one variable
  change per finger length (index/middle/ring/pinky ≈ 80/88/82/65 mm).

## 2. TPU print settings (95A, e.g. Overture/Polymaker/eSUN TPU)

**Dry the filament first — 6–8 h at 55 °C.** Wet TPU is the #1 cause of
stringing, weak layer bonds, and popping. This matters more than any slicer
setting below.

| Setting | Value | Notes |
|---|---|---|
| Nozzle temp | 225–235 °C | Higher end for better layer adhesion (flexures live or die on this) |
| Bed temp | 40–50 °C | TPU sticks aggressively to PEI — use glue stick as a *release* layer |
| Print speed | 25–35 mm/s (Bowden: 15–20) | Direct-drive strongly preferred; modern CoreXY (Bambu/Voron) can run 50+ |
| Layer height | 0.2 mm | 0.15 mm for smoother flexure surfaces |
| Perimeters | 2 | Walls of the fin-ray ARE the part — set wall thickness in CAD as a multiple of (2 × 0.42 mm line width) |
| Infill | 0–10 % | The rib truss replaces infill; interior voids should stay empty |
| Retraction | 0.5–1 mm @ 25 mm/s (direct drive) | Disable coasting/wipe; enable "avoid crossing perimeters" to cut stringing |
| Fan | 30–50 % after layer 2 | Full fan weakens layer bonds |
| Flow | 105–110 % | TPU under-extrudes at speed; calibrate with a wall-thickness test |

### Print orientation — critical
Print the finger **lying on its side face** (side profile flat on the bed).
The walls and ribs are then continuous extrusion paths in the XY plane, and
bending stress runs *along* layer lines, not across them. Printed upright,
the finger will delaminate at a rib junction within a few hundred cycles.
No supports needed in this orientation.

### Quick calibration part
Before printing full fingers, print one 20 mm-wide test coupon: a 1.0 mm wall,
50 mm tall, lying flat. Flex it 50 times and check wall thickness with
calipers. Adjust flow until measured = designed ±0.05 mm.

## 3. Rigid parts (palm, whiffle-tree, servo mount)

| Setting | Value |
|---|---|
| Material | PETG (tougher) or PLA+ (easier) |
| Perimeters / infill | 4 walls, 30 % gyroid |
| Layer height | 0.2 mm |
| Pivot pins | M3 bolts or 1.75 mm filament rivets (melt heads with a lighter) |
| Hole compensation | Model holes +0.2 mm; TPU holes +0.4 mm (elastic recovery shrinks them) |
| Clearances | 0.3 mm for press-fit into TPU, 0.5 mm for free-moving pivots |

Whiffle-tree: a 40 mm rocker bar per finger pair, pivoted at its midpoint,
cascading to a central bar on the servo horn. Two levels of rockers balance
four fingers off one servo automatically.

## 4. Fingertip pad molds
- Print 2-piece molds in PLA at 0.12 mm layers, smooth with a heat gun pass.
- Pour Ecoflex 00-30 or Dragon Skin 10; a 3–4 mm pad thickness on the distal
  third of the front wall is enough.
- Key the pad into the TPU with 2–3 dovetail slots modeled into the front
  wall — silicone doesn't glue well to TPU (use Sil-Poxy if you need adhesive).

## 5. First test protocol
1. Grasp set: egg, 500 ml bottle, pen, sheet of paper, apple.
2. Measure fingertip force with a kitchen scale (target 5–15 N per finger).
3. Cycle test: 500 open/close cycles, then inspect rib junctions for cracks.
4. Log which geometry variant (wall thickness / rib angle) you printed —
   change one parameter per iteration.

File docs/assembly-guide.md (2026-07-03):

# Assembly Guide

Step-by-step build of the flexible prosthetic hand, in the order the
`ROADMAP.md` phases expect. Times assume parts are printed and the BOM is on
hand.

## Tools & consumables
- 3D printer (direct-drive preferred for TPU), filament dryer
- Soldering iron, heat-shrink, 100 Ω / 330 Ω / 1 kΩ / 10 kΩ resistors
- M3 hardware: socket screws (6–16 mm), grub screws, nyloc nuts, heat-set inserts
- Soldering iron tip for heat-set inserts
- Fishing-line crimps + crimp pliers, or practice the Palomar knot
- Multimeter; kitchen scale (fingertip-force check)
- Silicone: Ecoflex 00-30, mixing cups, gram scale

## Step 1 — Print everything
| Part | File | Material | Qty |
|---|---|---|---|
| Fingers | `cad/finray_finger.scad` (80/88/82/65 mm) | TPU 95A | 4 |
| Thumb | `cad/finray_finger.scad` (80 mm) | TPU 95A | 1 |
| Palm chassis | `cad/palm_chassis.scad` | PETG/PLA+ | 1 |
| Whiffle-tree | `cad/whiffletree.scad` | PETG/PLA+ | 1 plate |
| Wrist adapter | `cad/wrist_socket.scad` (`part="adapter"`) | PETG | 1 |
| Socket cuff | `cad/wrist_socket.scad` (`part="cuff"`) | TPU 95A | 1 |
| Pad mold | `cad/finray_finger.scad` (`part="mold"`) | PLA | 1 |

Dry the TPU first. Print fingers **lying on their side face** (as modeled).

## Step 2 — Heat-set inserts & fastener test
Install M3 heat-set inserts in the palm's servo-mount and wrist bolt bosses.
Verify a finger base slides into its palm pocket and the two cross-holes line
up with the base holes; ream with a 3.2 mm bit if tight (TPU shrinks holes).

## Step 3 — Silicone fingertip pads
1. Mix Ecoflex 00-30 1:1 by weight, degas if you have a chamber (optional).
2. Pour ~3.5 mm into the pad mold; press the finger's distal third in so the
   dovetail keys fill. Cure 4 h at room temp (or 10 min at 60 °C).
3. Demold; the pad is mechanically keyed — Sil-Poxy only if it lifts.

## Step 4 — Tendons
1. Cut UHMWPE braid ~1.5× finger+palm length per finger.
2. Thread PTFE liner through each finger's back-wall channel and the palm
   routing holes.
3. Anchor at the fingertip: pass braid through the tip cross-hole, tie a
   figure-8 stopper (or crimp around a smooth post).
4. Route the free end through the palm to its whiffle-tree rocker slot; leave
   slack — tensioning comes after the servo is in.

## Step 5 — Whiffle-tree + servo
1. Bolt the two secondary rockers to the primary rocker's ends via M3 +
   nyloc, pivoting **freely** (do not overtighten — they must rotate).
2. Attach the primary rocker's drive tab to the servo horn.
3. Drop the STS3215 into the palm pocket; secure with M3 into inserts.
4. Set servo ID = 1 and 1 Mbps with a Feetech/Waveshare config tool before
   final assembly (or over the same bus from the firmware).

## Step 6 — Tension the tendons
1. Power the servo, send `o` (open) so the horn is at `POS_OPEN`.
2. Pull each tendon just taut (no finger curl yet), clamp under the rocker
   grub screw.
3. Send `c` / `o` a few times; adjust each grub screw until all fingers
   start and finish together. **Re-check after a day** — UHMWPE creeps.

## Step 7 — Electronics
Wire per `wiring-schematic.md`. Build the two MOSFET switches with flyback
diodes. Do a **smoke test at low voltage** first: 5 V bench supply, confirm
the ESP32 enumerates and `?` returns a status line before connecting the
Li-ion pack.

## Step 8 — Jamming pad (Phase 4)
1. Fill a latex balloon ~70 % with dry ground coffee; knot around a barbed
   tube stub; seat it in the palm recess.
2. Route the tube through the palm pass-through to the 3-way solenoid and
   pump.
3. Test: send `j` — the pad should firm up in ~1.5 s; `v` — it goes floppy.

## Step 9 — Wrist & socket
1. Bolt the wrist adapter to the palm's proximal bolt circle (wire pass-
   through aligned to the servo cable exit).
2. Slide the socket cuff's dovetail onto the adapter; add straps.
3. Optional compliant wrist: sandwich a 6 mm TPU disc between adapter and
   palm (`wrist_socket.scad` note).

## Step 10 — Commissioning
Follow `ROADMAP.md` Phase 2 exit criteria (grasp set), then Phase 3 for EMG:
send `e`, do the relax/squeeze calibration, and test open/close. Log telemetry
with `software/emg_collect.py` and validate against `test-protocol.md`.

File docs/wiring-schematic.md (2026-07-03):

# Wiring Schematic

Complete electrical connections for the hand controller. Companion to
`../architecture.md` §3 and `../firmware/README.md`.

## Block diagram

```
                    ┌──────────────────────── 2S Li-ion pack (7.4–12 V) ───────────────────────┐
                    │                                                                            │
              ┌─────┴─────┐                                                                      │
              │    BMS    │  (≥5 A, over-current + over-discharge protection)                    │
              └─────┬─────┘                                                                      │
        VBAT ───────┼──────────────┬───────────────┬────────────────┐                           │
                    │              │               │                │                           │
              ┌─────▼─────┐   ┌────▼────┐    ┌──────▼──────┐  ┌──────▼──────┐                     │
              │ Buck 5 V  │   │ STS3215 │    │ Pump (via   │  │ Solenoid    │                     │
              │  (3 A)    │   │  servo  │    │  MOSFET Q1) │  │ (via MOSFET │                     │
              └──┬────┬───┘   └────┬────┘    └──────┬──────┘  │   Q2)       │                     │
                 │    │            │ 1-wire         │         └──────┬──────┘                     │
              5V │    │ 5V         │ TTL bus        │ gate           │ gate                       │
                 │    │            │                │                │                            │
        ┌────────▼──┐ │      ┌─────▼─────────────────────────────────────────────┐               │
        │ MyoWare2.0│ │      │                  ESP32-S3                          │               │
        │  ENV out ─┼─┼──────► GPIO4 (ADC1_CH3)                                   │               │
        └───────────┘ │      │  GPIO17 (TX1) ──[1kΩ]──┐                           │               │
                      │      │  GPIO18 (RX1) ─────────┴──► STS3215 data           │               │
                      └──────► 3V3 / VIN (USB or buck)                            │               │
                             │  GPIO5  ──────────────────► Q1 gate (pump)         │               │
                             │  GPIO6  ──────────────────► Q2 gate (solenoid)     │               │
                             │  GPIO7  ◄── button ── GND                          │               │
                             │  GPIO15 ──────────────────► LED ──[330Ω]── GND     │               │
                             │  GND ─────────────────────────────────────────────┼───────────────┘
                             └──────────────────────────────────────────────────-┘
                                        (common ground tie — REQUIRED)
```

## Half-duplex servo bus (the one non-obvious part)

The STS3215 talks on a **single data wire**. To drive it from a normal UART:

```
ESP32 GPIO17 (TX1) ──[1 kΩ]──┬──► STS3215 DATA
ESP32 GPIO18 (RX1) ──────────┘
```

- TX idles HIGH. When the ESP32 sends, the 1 kΩ resistor is weak enough that
  the servo can still pull the line for its reply; RX reads both our echo and
  the response. The firmware's `drainEcho()` discards our own transmitted
  bytes before parsing the reply.
- Tidy alternative: a **Waveshare Bus Servo Adapter (~$6)** does the direction
  switching in hardware — wire GPIO17→TX, GPIO18→RX, and skip the resistor.

## MOSFET low-side switches (pump & solenoid)

Both inductive loads use a logic-level N-channel MOSFET (IRLZ44N, AO3400, or a
ready-made MOSFET module):

```
VBAT ──► load(+)
         load(−) ──► MOSFET drain
                     MOSFET source ──► GND
         GPIO ──[100Ω]──► MOSFET gate,  gate ──[10kΩ]──► GND (pulldown)
   flyback diode (1N4007 / SS34) across the load, cathode to VBAT
```

The flyback diode is mandatory — without it the coil's collapse spike will
reset or damage the ESP32.

## Connection table

| From | To | Wire |
|---|---|---|
| BMS VBAT+ | Servo V+, Buck IN+, Pump+, Solenoid+ | 20 AWG |
| BMS VBAT− | Common ground rail | 20 AWG |
| Buck 5 V | MyoWare VIN, (optional ESP32 VIN) | 24 AWG |
| ESP32 GPIO17 | 1 kΩ → STS3215 data | 26 AWG |
| ESP32 GPIO18 | STS3215 data | 26 AWG |
| ESP32 GPIO4 | MyoWare ENV | shielded if long |
| ESP32 GPIO5/6 | Q1/Q2 gate (100 Ω series) | 26 AWG |
| ESP32 GPIO7 | Button → GND | 26 AWG |
| ESP32 GPIO15 | LED anode (330 Ω) | 26 AWG |
| ESP32 GND | Common ground rail | 22 AWG |

## Safety notes
- **Common ground** between the servo/pump supply and the ESP32 is required or
  the serial bus and MOSFET gates float.
- Fuse VBAT at ~5 A right after the BMS.
- Never back-power the servo from the ESP32 5 V pin — it can't source stall
  current and will brown out.
- On brown-out the ESP32 reboots with the servo torque-off; the hand goes
  **passively compliant** rather than clamping — a safety property of the soft
  design (`../architecture.md` §7).

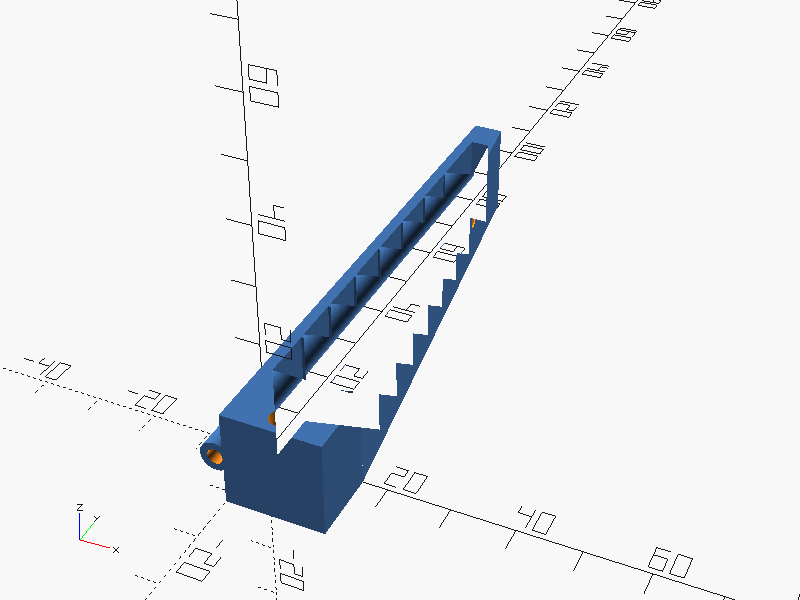
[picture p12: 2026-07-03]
build/png/finger_graded.png

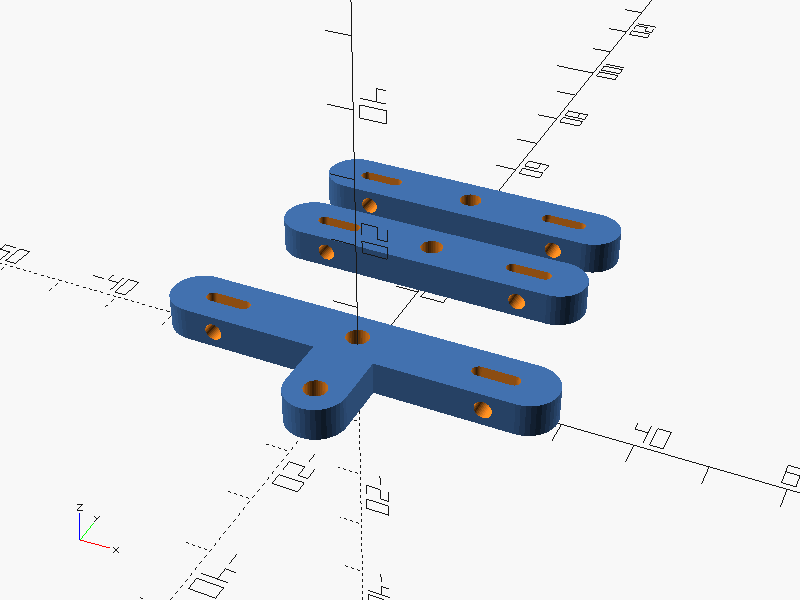
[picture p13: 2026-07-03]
build/png/whiffletree.png

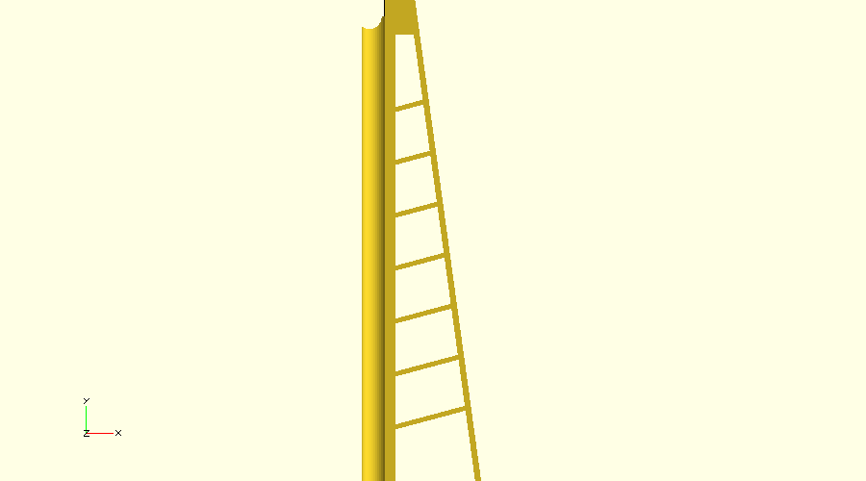
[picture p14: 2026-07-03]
build/png/finger_side.png

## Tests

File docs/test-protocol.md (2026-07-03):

# Test & Validation Protocol

Objective, repeatable tests mapped to the `ROADMAP.md` phase exit criteria.
Record every run in a build log; change **one** parameter per iteration.

## T1 — Finger flow calibration (Phase 1)
- **Setup:** print the 20 mm wall coupon (`finray-cad-print-parameters.md` §2).
- **Measure:** wall thickness with calipers at 5 points.
- **Pass:** measured = designed ±0.05 mm. If not, adjust flow % and reprint.

## T2 — Passive wrap (Phase 1)
- **Setup:** clamp finger base; no tendon.
- **Action:** press a 20 mm rod against the mid-finger front wall with ~5 N.
- **Pass:** tip deflects **toward** the rod (wrapping), not away. If it bows
  outward, front wall is too thick relative to back wall — reduce `front_wall_t`.

## T3 — Fingertip force (Phase 1)
- **Setup:** finger + tendon; tip resting on a kitchen scale.
- **Action:** pull tendon to full servo travel (or by hand to the same length).
- **Measure:** peak force (N = grams × 0.0098).
- **Pass:** 5–15 N. Below 5 N → thicker back wall or shorter finger; above 15 N
  with poor conformity → thinner front wall / floating ribs.

## T4 — Fatigue (Phase 1)
- **Action:** 500 open/close cycles (script the servo or use a cam).
- **Inspect:** rib-to-wall junctions for cracks/whitening; tendon channel wear.
- **Pass:** no visible cracking; fingertip force within 15 % of pre-test.
  Failure here almost always means wrong print orientation — reprint on side.

## T5 — Differential balance (Phase 2)
- **Setup:** full hand, tendons tensioned.
- **Action:** hold a flat card against two fingers, close the hand.
- **Pass:** free fingers keep closing after the blocked ones stall (whiffle-
  tree routing works); all fingers reach the object surface within ~0.3 s of
  each other on an irregular object.

## T6 — Grasp set (Phase 2 exit)
Objects: egg, 500 ml bottle, pen, sheet of paper, apple.
- **Action:** close on each; lift and hold 30 s.
- **Measure:** servo `present_load` at hold (telemetry).
- **Pass:** ≥4/5 held for 30 s at ≤60 % load. Egg must not crack (tune
  `GRIP_LOAD` down); paper must be pinchable (thumb opposition + pad friction).

## T7 — EMG open/close reliability (Phase 3 exit)
- **Setup:** MyoWare on forearm flexor; run boot calibration.
- **Action:** 20 close attempts + 20 open attempts, natural muscle effort.
- **Measure:** success rate; false triggers per minute at rest.
- **Pass:** >90 % intended actions succeed; <1 false trigger/min at rest over
  a 10-min session with no recalibration. Tune `CLOSE_FRACTION` from
  `emg_train.py` MAV bands; increase `DEBOUNCE_MS` if jittery.

## T8 — Classifier quality (Phase 3, optional ML)
- **Action:** collect 30 s each of rest/close/open; `python emg_train.py`.
- **Pass:** per-class F1 ≥ 0.85 on the held-out split; if `open` is weak,
  collect more co-contraction examples or add a channel.

## T9 — Variable stiffness (Phase 4 exit)
- **Action A (soft):** grasp an egg unjammed → must not crack.
- **Action B (rigid):** grasp a 2 kg bag handle; auto-jam triggers on load →
  hand holds without the fingers splaying.
- **Measure:** pad rigidity by pressing a finger — noticeably firmer jammed.
- **Pass:** both A and B succeed with **no manual mode switch** (firmware
  auto-stiffens on sustained load, vents on release).

## T10 — Fail-soft (safety)
- **Action:** cut servo power mid-grasp.
- **Pass:** hand relaxes to passive compliance (does not clamp or lock). This
  is the intended failure mode of the soft design.

## T11 — Endurance (pre-wearable, Phase 5)
- **Action:** 5000 grasp cycles on the bottle; re-tension check daily.
- **Pass:** grip force within 20 % of start; no tendon failure; document
  UHMWPE creep take-up needed (informs the re-tensioning interval).

## Build-log template
```
date | phase | change made | test | result | pass/fail | notes
```

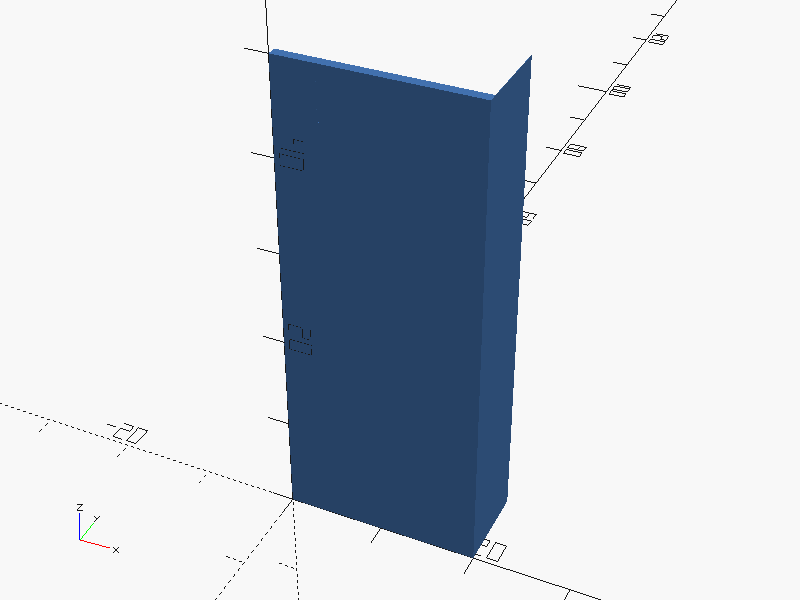
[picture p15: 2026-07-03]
build/png/calibration_coupon.png

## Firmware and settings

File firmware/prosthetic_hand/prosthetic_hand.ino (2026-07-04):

// ============================================================
// Flexible prosthetic hand — ESP32-S3 control firmware
//
// Hardware: Feetech STS3215 on UART1 (half-duplex TTL),
//           MyoWare 2.0 envelope on ADC, pump + 3-way valve
//           on MOSFET gates for the granular-jamming pad.
//
// Control loop @100 Hz, telemetry CSV @10 Hz over USB serial.
// Serial commands (115200): o=open c=close g<0-100>=grip effort
//                           j=jam v=vent e=toggle EMG mode ?=status
//
// See ../../architecture.md §4 for the state machine spec and
// ../README.md for wiring.
// ============================================================

#include <Arduino.h>
#include "sts_servo.h"

// ---------------- pins ----------------
constexpr int PIN_SERVO_TX = 17;
constexpr int PIN_SERVO_RX = 18;
constexpr int PIN_EMG      = 4;   // ADC1_CH3, MyoWare ENV out
constexpr int PIN_PUMP     = 5;
constexpr int PIN_VALVE    = 6;   // energized = sealed, off = vent
constexpr int PIN_BUTTON   = 7;   // INPUT_PULLUP, manual open/close
constexpr int PIN_LED      = 15;

// ---------------- servo ----------------
constexpr uint8_t  SERVO_ID       = 1;
constexpr uint16_t POS_OPEN       = 1024;  // calibrate on assembly
constexpr uint16_t POS_CLOSED     = 3072;  // ~120 deg sweep
constexpr uint16_t CLOSE_STEP     = 12;    // ticks per 10ms => ~1.7s full close
constexpr int      GRIP_LOAD      = 350;   // present-load units, stop-closing threshold
constexpr int      JAM_LOAD       = 600;   // auto-stiffen threshold
constexpr int      OVERLOAD       = 900;   // back off above this
constexpr uint32_t JAM_DWELL_MS   = 1000;  // sustained high load before jamming
constexpr uint32_t PUMP_MS        = 1500;  // pump run time to evacuate the pad

// ---------------- EMG ----------------
constexpr uint32_t CALIB_MS        = 3000;
constexpr float    CLOSE_FRACTION  = 0.35; // of calibrated dynamic range
constexpr uint32_t DEBOUNCE_MS     = 150;
constexpr uint32_t DOUBLE_PULSE_MS = 600;  // two pulses inside this = open intent

enum State { ST_OPEN, ST_CLOSING, ST_HOLDING, ST_RELEASING };
const char *STATE_NAMES[] = {"OPEN", "CLOSING", "HOLDING", "RELEASING"};

StsServo servo(Serial1, SERVO_ID);

State    state         = ST_OPEN;
bool     emgMode       = false;
bool     jammed        = false;
uint16_t goalPos       = POS_OPEN;
int      gripLoadLimit = GRIP_LOAD;
float    emgFloor = 0, emgMax = 1;
float    emgEnv = 0;
uint32_t loadHighSince = 0, pumpOffAt = 0, lastPulseAt = 0, pulseStartAt = 0;
bool     pulseActive = false;

// 20-sample moving average over the MyoWare envelope
float emgSample() {
  static float buf[20] = {0};
  static int   idx = 0;
  static float sum = 0;
  float v = analogReadMilliVolts(PIN_EMG);
  sum += v - buf[idx];
  buf[idx] = v;
  idx = (idx + 1) % 20;
  return sum / 20.0f;
}

void calibrateEmg() {
  Serial.println("# EMG calibration: relax 3s...");
  uint32_t t0 = millis();
  float acc = 0; int n = 0;
  while (millis() - t0 < CALIB_MS) { acc += emgSample(); n++; delay(10); }
  emgFloor = acc / n;
  Serial.println("# now one strong squeeze (3s window)...");
  t0 = millis(); emgMax = emgFloor + 50; // minimum sane range
  while (millis() - t0 < CALIB_MS) { emgMax = max(emgMax, emgSample()); delay(10); }
  Serial.printf("# calibrated floor=%.0f max=%.0f mV\n", emgFloor, emgMax);
}

// Returns +1 close intent, -1 open intent, 0 none.
int emgIntent() {
  float thresh = emgFloor + CLOSE_FRACTION * (emgMax - emgFloor);
  bool above = emgEnv > thresh;
  uint32_t now = millis();

  if (above && !pulseActive) { pulseActive = true; pulseStartAt = now; }
  if (!above && pulseActive && now - pulseStartAt > DEBOUNCE_MS) {
    pulseActive = false;
    // quick double pulse => open; otherwise a completed pulse arms close
    if (now - lastPulseAt < DOUBLE_PULSE_MS) { lastPulseAt = 0; return -1; }
    lastPulseAt = now;
  }
  // sustained squeeze (not a quick pulse) => close
  if (pulseActive && now - pulseStartAt > 2 * DEBOUNCE_MS) return +1;
  return 0;
}

void jamStart() {
  digitalWrite(PIN_VALVE, HIGH);          // seal
  digitalWrite(PIN_PUMP, HIGH);           // evacuate
  pumpOffAt = millis() + PUMP_MS;
  jammed = true;
}

void jamVent() {
  digitalWrite(PIN_PUMP, LOW);
  digitalWrite(PIN_VALVE, LOW);           // 3-way vents to atmosphere
  jammed = false;
}

void enterState(State s) {
  state = s;
  if (s == ST_RELEASING) jamVent();       // always vent before opening
}

void fsmStep(int intent) {
  int load = servo.presentLoad();
  uint32_t now = millis();

  switch (state) {
    case ST_OPEN:
      if (intent > 0) enterState(ST_CLOSING);
      break;

    case ST_CLOSING:
      if (intent < 0) { enterState(ST_RELEASING); break; }
      goalPos = min<uint16_t>(goalPos + CLOSE_STEP, POS_CLOSED);
      if (load > gripLoadLimit || goalPos >= POS_CLOSED) enterState(ST_HOLDING);
      break;

    case ST_HOLDING:
      if (intent < 0) { enterState(ST_RELEASING); break; }
      if (load > OVERLOAD) goalPos = max<uint16_t>(goalPos - CLOSE_STEP, POS_OPEN);
      // auto-stiffen on sustained heavy load (e.g. carrying a bag)
      if (load > JAM_LOAD) {
        if (loadHighSince == 0) loadHighSince = now;
        else if (!jammed && now - loadHighSince > JAM_DWELL_MS) jamStart();
      } else loadHighSince = 0;
      break;

    case ST_RELEASING:
      goalPos = max<uint16_t>(goalPos - 3 * CLOSE_STEP, POS_OPEN);
      if (goalPos <= POS_OPEN) enterState(ST_OPEN);
      break;
  }

  if (jammed && pumpOffAt && now > pumpOffAt) {  // valve holds the vacuum
    digitalWrite(PIN_PUMP, LOW);
    pumpOffAt = 0;
  }
  servo.setGoalPosition(goalPos);
}

int dispatchCommand(const String &cmd) {
  if (cmd == "c") return +1;
  if (cmd == "o") return -1;
  if (cmd == "j") { jamStart(); return 0; }
  if (cmd == "v") { jamVent();  return 0; }
  if (cmd == "e") {
    emgMode = !emgMode;
    if (emgMode) calibrateEmg();
    Serial.printf("# EMG mode %s\n", emgMode ? "ON" : "OFF");
    return 0;
  }
  if (cmd.startsWith("g")) {  // grip effort 0-100 -> load limit
    int pct = constrain(cmd.substring(1).toInt(), 0, 100);
    gripLoadLimit = GRIP_LOAD + (OVERLOAD - GRIP_LOAD) * pct / 100;
    Serial.printf("# grip load limit=%d\n", gripLoadLimit);
    return 0;
  }
  if (cmd == "?")
    Serial.printf("# state=%s pos=%d load=%d jammed=%d emg=%d\n",
                  STATE_NAMES[state], servo.presentPosition(),
                  servo.presentLoad(), jammed, emgMode);
  return 0;
}

// Non-blocking command reader. Accumulates bytes into a bounded buffer and
// only dispatches on a complete line — NEVER blocks the 100 Hz control loop
// waiting for a newline (a partial/withheld serial line must not stall an
// actuator strapped to a limb). Oversized lines are dropped, not overflowed.
int serialIntent() {
  static char buf[24];
  static uint8_t len = 0;
  while (Serial.available()) {
    char ch = Serial.read();
    if (ch == '\n' || ch == '\r') {
      if (len == 0) continue;          // ignore blank lines / CRLF pairs
      buf[len] = '\0';
      String cmd(buf);
      len = 0;
      cmd.trim();
      int intent = dispatchCommand(cmd);
      if (intent != 0) return intent;  // surface open/close immediately
    } else if (len < sizeof(buf) - 1) {
      buf[len++] = ch;
    } else {
      len = 0;                         // overrun guard: discard the line
    }
  }
  return 0;
}

void setup() {
  Serial.begin(115200);
  Serial1.begin(1000000, SERIAL_8N1, PIN_SERVO_RX, PIN_SERVO_TX);
  pinMode(PIN_PUMP, OUTPUT);
  pinMode(PIN_VALVE, OUTPUT);
  pinMode(PIN_BUTTON, INPUT_PULLUP);
  pinMode(PIN_LED, OUTPUT);
  analogReadResolution(12);
  jamVent();
  servo.setGoalPosition(POS_OPEN);
  Serial.println("# prosthetic hand v1 — 'e' for EMG mode, '?' for status");
  Serial.println("millis,emg_raw,emg_env,state,servo_pos,servo_load,jammed");
}

void loop() {
  static uint32_t lastTick = 0, lastTelem = 0;
  uint32_t now = millis();
  if (now - lastTick < 10) return;      // 100 Hz superloop
  lastTick = now;

  emgEnv = emgSample();

  int intent = serialIntent();
  if (emgMode && intent == 0) intent = emgIntent();
  if (digitalRead(PIN_BUTTON) == LOW)   // manual override button
    intent = (state == ST_OPEN) ? +1 : -1;

  fsmStep(intent);

  digitalWrite(PIN_LED, state == ST_HOLDING ? HIGH : (now / 500) % 2);

  if (now - lastTelem >= 100) {         // 10 Hz telemetry CSV
    lastTelem = now;
    Serial.printf("%lu,%d,%.0f,%d,%d,%d,%d\n",
                  now, analogRead(PIN_EMG), emgEnv, (int)state,
                  servo.presentPosition(), servo.presentLoad(), jammed);
  }
}

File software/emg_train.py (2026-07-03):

#!/usr/bin/env python3
"""Train a gesture classifier from labeled EMG sessions.

Reads data/<label>.csv files produced by emg_collect.py, windows the
envelope signal, extracts standard EMG time-domain features, trains a
RandomForest, prints a confusion matrix, and emits firmware-ready
constants. Optional TFLite export path is documented at the bottom.

    python emg_train.py --datadir data --labels rest close open

Requires: numpy, scikit-learn (pip install numpy scikit-learn).
A synthetic self-test runs if no data files are found:
    python emg_train.py --selftest
"""
import argparse
import glob
import os
import sys

import numpy as np

WINDOW = 4      # samples per window (~400 ms at 10 Hz telemetry)
STRIDE = 2      # 50% overlap
ENV_COL = 2     # emg_env column index in the CSV


# ---------------- feature extraction ----------------
def features(window):
    """Standard EMG time-domain features over one window of envelope values."""
    w = np.asarray(window, dtype=float)
    diff = np.diff(w) if len(w) > 1 else np.array([0.0])
    mav = np.mean(np.abs(w))                      # mean absolute value
    rms = np.sqrt(np.mean(w ** 2))                # root mean square
    wl = np.sum(np.abs(diff))                     # waveform length
    zc = np.sum(np.abs(np.sign(w[:-1] - np.mean(w))
                       - np.sign(w[1:] - np.mean(w))) > 0) if len(w) > 1 else 0
    return [mav, rms, wl, float(zc)]


def windowize(series, label):
    X, y = [], []
    for i in range(0, len(series) - WINDOW + 1, STRIDE):
        X.append(features(series[i:i + WINDOW]))
        y.append(label)
    return X, y


def load_dataset(datadir, labels):
    X, y = [], []
    for label in labels:
        path = os.path.join(datadir, f"{label}.csv")
        if not os.path.exists(path):
            print(f"! missing {path}, skipping")
            continue
        data = np.genfromtxt(path, delimiter=",", skip_header=1)
        if data.ndim == 1:
            data = data.reshape(1, -1)
        env = data[:, ENV_COL]
        Xi, yi = windowize(env, label)
        X.extend(Xi)
        y.extend(yi)
        print(f"  {label}: {len(yi)} windows from {len(env)} samples")
    return np.array(X), np.array(y)


def train(X, y):
    from sklearn.ensemble import RandomForestClassifier
    from sklearn.metrics import classification_report, confusion_matrix
    from sklearn.model_selection import train_test_split

    Xtr, Xte, ytr, yte = train_test_split(
        X, y, test_size=0.25, random_state=0, stratify=y)
    clf = RandomForestClassifier(n_estimators=100, max_depth=8, random_state=0)
    clf.fit(Xtr, ytr)
    pred = clf.predict(Xte)

    print("\n=== confusion matrix ===")
    print("labels:", sorted(set(y)))
    print(confusion_matrix(yte, pred, labels=sorted(set(y))))
    print("\n=== report ===")
    print(classification_report(yte, pred))
    return clf


def emit_thresholds(X, y):
    """Print simple per-class MAV bands the firmware can use without ML."""
    print("=== firmware threshold hints (envelope MAV per class) ===")
    for label in sorted(set(y)):
        mav = X[y == label][:, 0]
        print(f"  {label:8s}: MAV mean={mav.mean():7.1f}  "
              f"p10={np.percentile(mav, 10):7.1f}  "
              f"p90={np.percentile(mav, 90):7.1f}")
    print("# Set CLOSE_FRACTION so its threshold sits between rest.p90 "
          "and close.p10.")


def selftest():
    """Synthetic three-class data so the pipeline runs with no hardware."""
    rng = np.random.default_rng(0)
    rest = rng.normal(120, 15, 300)
    close = rng.normal(600, 60, 300)
    openg = np.concatenate([rng.normal(500, 50, 150), rng.normal(120, 15, 150)])
    X, y = [], []
    for series, label in [(rest, "rest"), (close, "close"), (openg, "open")]:
        Xi, yi = windowize(series, label)
        X.extend(Xi)
        y.extend(yi)
    return np.array(X), np.array(y)


def main():
    ap = argparse.ArgumentParser(description=__doc__)
    ap.add_argument("--datadir", default="data")
    ap.add_argument("--labels", nargs="+", default=["rest", "close", "open"])
    ap.add_argument("--selftest", action="store_true")
    args = ap.parse_args()

    if args.selftest or not glob.glob(os.path.join(args.datadir, "*.csv")):
        if not args.selftest:
            print("No data files found — running synthetic self-test.\n")
        X, y = selftest()
    else:
        X, y = load_dataset(args.datadir, args.labels)

    if len(X) < 10:
        sys.exit("Not enough windows to train.")

    train(X, y)
    emit_thresholds(X, y)

    print("\n# TFLite-Micro upgrade path: replace RandomForest with a small "
          "Keras MLP (Dense 16->8->3), then `tflite_convert` and embed the "
          ".tflite as a C array for TensorFlow Lite Micro on the ESP32-S3.")


if __name__ == "__main__":
    main()

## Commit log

2026-07-03 Add fin-ray finger CAD and 3D-print parameter guide
    Claude-Session: https://claude.ai/code/session_0177kgv82V17uXpUbqpdNeuX
2026-07-03 Add full project package: roadmap, architecture, CAD, firmware, EMG software
    - ROADMAP.md: 6-phase development plan with exit criteria
    - architecture.md: mechanical/electrical/firmware/software architecture + diagrams
    - cad/: parametric OpenSCAD fin-ray finger, whiffle-tree differential, pad mold
    - firmware/: ESP32-S3 grasp state machine, STS3215 driver, EMG intent, jamming control
    - software/: EMG collection + gesture-classifier training pipeline (verified)
    - README.md: project overview and quick start
    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
    [finray_finger.scad, whiffletree.scad]
2026-07-03 Add palm/wrist CAD, wiring schematic, assembly & test docs, cycle-test script
    - cad/palm_chassis.scad: palm with finger/thumb mounts, servo pocket, jamming recess
    - cad/wrist_socket.scad: wrist adapter + parametric forearm socket cuff
    - docs/wiring-schematic.md: full electrical schematic, half-duplex bus, MOSFET switches
    - docs/assembly-guide.md: 10-step build from print to commissioning
    - docs/test-protocol.md: T1-T11 validation tests mapped to roadmap exit criteria
    - software/cycle_test.py: automated open/close cycling for fatigue tests
    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
    [palm_chassis.scad, wrist_socket.scad]
2026-07-03 Phase 0/1: procurement checklist, rendered STLs, print package
    Phase 0 (toolchain + design side):
    - PROCUREMENT.md: starter BOM order checklist + toolchain setup/verify
    - cad/render_all.sh: reproducible render with manifold check on every part
    - Installed/validated OpenSCAD; EMG pipeline passes --selftest
    Phase 1 (single-finger design + export):
    - cad/calibration_coupon.scad: TPU flow-calibration coupon
    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
    [calibration_coupon.scad, calibration_coupon.stl, finger_floating.stl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]
2026-07-04 Add attack-surface inventory, maintenance skill, and assessment workflow
    - attacksurface.md: living security inventory of the 4 evidenced surfaces
    (GitHub repo, ESP32-S3 firmware, EMG toolchain, EMG biometric data) with
    tech/hosting/auth/exposure/defenses/misconfigs/findings per system, plus
    explicit placeholders for external categories not yet in scope. Secret scan
    run and recorded clean.
    - .claude/skills/attack-surface: skill defining the entry schema and rules for
    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
2026-07-04 Reconcile attack-surface inventory with assessment; fix serial-loop stall
    Fold verified findings from the AssessAttackSurface run (83 agents) + manual
    cross-check into attacksurface.md:
    - Exposures verified: firmware physical-only (no radio init), tooling/data
    local-only (no sockets); secret-clean across all history; no CI/CD
    - New/confirmed findings: plaintext-HTTP git remote (loopback), servo-bus
    load values trusted by grasp FSM, no secure boot/flash encryption, no
    authorization tiers, unpinned deps+toolchain, --label path traversal,
    plaintext biometric EMG at rest
    - Per-surface test cadences set from criticality x cost
    Firmware safety fix (found by the assessment): serialIntent()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
    [prosthetic_hand.ino]
